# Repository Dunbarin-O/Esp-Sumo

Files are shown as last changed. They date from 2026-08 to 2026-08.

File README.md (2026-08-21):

# Esp-Sumo
## Design Story

Building a custom mini-sumo robot sounded straightforward until i tried try wiring one together. Early in the process, I realized that relying on a disconnected stack of off-the-shelf motor drivers, sensor breakout boards, and external voltage regulators created a fragile spiderweb of jumper wires that easily disconnected during testing also pretty ugly, very ugly. To build something that stayed together, I decided to design a single, custom printed circuit board (PCB) to integrate every subsystem onto one reliable platform.

My first major challenge was in designing the power architecture. I initially planned to use two high-efficiency switching buck converters in series one to drop the 7.4V battery down to 5V, and a second to drop it further to 3.3V. While it looked ideal in block diagrams, routing the PCB layout showed that the second converter added significant cost, component count, and board space for a negligible boost in efficiency. I pivoted to a hybrid design: a single switching converter for high-draw 5V motor and servo demands, paired with a lightweight linear regulator for sensitive 3.3V logic. This trade-off taught me balancing performance, cost, and simplicity

Seeking external feedback proved equally transformative. After completing my first schematic draft, I had another hardware designer review my work. That peer review exposed critical real-world edge cases I had completely overlooked. To prevent catastrophic shorts during rapid battery swaps, I incorporated a low-resistance P-channel MOSFET switch for instant reverse-polarity protection. I also completely re-evaluated my motor drivers. My initial plan used tiny DRV8220 drivers to keep the board compact, but testing showed their high internal resistance caused severe overheating, and their strict overcurrent protection completely shut off power during motor stalls. I upgraded to dual DRV8870 drivers featuring active "current chopping." Instead of shutting down when pushing against an obstacle, the new drivers automatically throttle current to deliver maximum safe pushing force without crashing the battery rail.

When the fabricated boards arrived, the ESP32-S3 microcontroller powered on and flashed code over USB smoothly on the first try. However, physical hardware quickly revealed real-world oversights that software DRC checks could not predict. I had selected incorrect physical footprints for my pin headers in KiCad, meaning the OLED display could not plug directly into the board and required manual jumper wire reworks. Furthermore, placing every component on a single side made the overall PCB footprint far too large for a compact mini-sumo chassis.

This project proved that a circuit can look entirely correct in a schematic editor while real-world physics, ergonomics, and physical dimensions tell a different story. Version 1 was not perfect, but it served as a functional masterclass in circuit protection, component selection, and practical board layout. For Version 2, I am transitioning to a double-sided component layout to cut the board size in half while correcting all header footprints for a clean, plug-and-play assembly.
---

### Read Further

For detailed technical implementation, schematics, component calculations, PCB layout files, and manufacturing outputs, explore the rest of the repository which is still a wip :

* **`PCB/`** – Native KiCad design files:
  * `Mini_sumo.kicad_sch` – Schematic capture files.
  * `Mini_sumo.kicad_pcb` – PCB trace routing and board layout.
* **`Hardware/`** – Assembly and manufacturing outputs:
  * `Mini_sumo.zip` – Production Gerber & drill files for board fabrication.
  * `combined_bom.csv` – Bill of Materials listing all active and passive components.
  * `positions.csv` – Pick-and-Place (CPL / Centroid) file for automated SMT assembly.
Project is in
 its early stages 

A low-cost, open-source motion control board for ESP32-based robots.
High-performance motor boards are usually expensive or made for just one job. This project is a low-cost, all-in-one board that lets you build precise small robots without needing extra shields or breakout boards.

Applications:

Mini Sumo Robots: Integrated motor control and gyro feedback for rapid opponent tracking and high-torque maneuvers.

Inverted Pendulum / Self-Balancing: Direct IMU integration for low-latency loop control and pitch stabilization.

Heading-Corrected Rovers: Closed-loop yaw monitoring for straight-line differential driving and precise turn angles.

### V1 Key Features

* **Dual High-Current Motor Drivers:** Two TI DRV8870 ICs providing independent PWM speed and direction control, supporting up to 3.6 A peak output per channel.
* **Onboard Motion Sensing:** MPU-6050 6-axis gyroscope and accelerometer connected via I2C for pitch, roll, and yaw feedback.
* **Integrated Diagnostic Display Header:** Dedicated 4-pin I2C header positioned for direct SSD1306 OLED screens (128x64 or 128x32).
* **User Input Controls:** 3 onboard tactical pushbuttons mapped to ESP32 GPIOs for mode selection, calibration, and menu navigation.
* **Built-in Servo Mount & Header:** Dedicated 3-pin PWM servo header (VCC, GND, Signal) with mounting holes integrated directly into the PCB outline (ideal for mini sumo flippers or sensor sweepers).
* **Optimized Power Architecture:** Designed for 2S (7.4V) LiPo input with onboard voltage regulation to safely power the ESP32, OLED, and logic components.
* **Expansion I/O:** Exposed GPIO headers for IR edge sensors, line detectors, or custom sensors.
* **100% Open-Source Hardware:** Full KiCad project files, schematics, PCB layouts, BOM, and manufacturing outputs (Gerbers/CPL) included.

 Top+null+SMT026081362981

| ESP32-S3 GPIO | Schematic net | Actually connected to |
| ---: | --- | --- |
| **GPIO0** | I00 | Boot button **SW3** + 10k pull-up |
| **GPIO1** | D1 | **Right IR sensor** J5 |
| **GPIO2** | D2 | **Left IR sensor** J6 |
| **GPIO3** | D3 | **SW4 button** |
| **GPIO4** | D4 | **Left edge sensor** J8 |
| **GPIO5** | D5 | **Right edge sensor** J10 |
| **GPIO6** | D6 | **SW5 button** |
| **GPIO7** | D7 | **SW6 button** |
| **GPIO8** | D8 | **Left motor driver IN2** |
| **GPIO9** | D9 | **Left motor driver IN1** |
| **GPIO10** | D10 | **J17 breakout pin 1** |
| **GPIO11** | D11 | **Gyro SCL** |
| **GPIO12** | D12 | **Gyro SDA** |
| **GPIO13** | D14 | **Right motor driver IN2** |
| **GPIO14** | D13 | **Right motor driver IN1** |
| **GPIO15** | D15 | **J15 / right motor?** |
| **GPIO16** | D16 | **J11 servo?** |
| **GPIO17** | D17 | **J17 software uvlo** |
| **GPIO18** | D18 | **Servo signal** |
| **GPIO19** | USB_D− | **USB D−** |
| **GPIO20** | USB_D+ | **USB D+** |
| **GPIO21** | — | **Unused** |

 ## Engineering Design Process & Iterations
## Power Design Choice: Dual Buck Converters vs. Buck + LDO

### First Attempt: Two-Stage Buck Regulation
My initial plan was to use two buck converters in series to drop the 7.4V (2S LiPo) battery voltage down to 5V, and then down to 3.3V for the system ICs to maximize energy efficiency.


**The Problem:** Each buck converter requires its own dedicated supporting passives (inductors, filter capacitors, and feedback resistors). Running two switching stages took up too much PCB footprint, added significant routing complexity, and increased the overall Bill of Materials (BOM) cost.

---

### Final Solution: Single Buck + 3.3V LDO Regulator
I simplified the power tree by keeping a single buck converter for the 5V rail and replacing the second buck stage with a straightforward 3.3V Low-Dropout (LDO) linear regulator.
 

## Peer Design Review: Power & Protection Enhancements

Following the V1 layout release, a community hardware review identified several critical power delivery and protection improvements to increase reliability:

### 1. Battery Input & System Protection
* **Circuit Protection:** The design was solid, but it lacked input safety. Adding an in-line fuse and a reverse-polarity protection circuit (e.g., a P-channel MOSFET or ideal diode) on the 2S LiPo rail is essential to prevent permanent board failure from accidental battery misplugs during quick pit stops.
* **Input Bulk Decoupling:** The 10 µF input capacitor ($C_{\text{IN}1}$) on the buck regulator followed basic bench-supply reference designs. However, long battery wire harnesses introduce parasitic inductance. Upgrading $C_{\text{IN}1}$ to a **47 µF ceramic + 10 µF ceramic paired with a 100 µF electrolytic** lowers High-Frequency ESR and prevents sudden motor current draw from sagging the shared battery rail and browning out the ESP32.

### 2. Switching Regulator Duty Cycle & Stability
* At 7.4 V nominal input, the 5 V buck converter operates near a **0.67 duty cycle** (higher as the LiPo drains). Because the regulator uses peak current mode with fixed internal compensation, switch-node signal integrity must be verified under full load with an oscilloscope to ensure stable loop performance across the entire discharge curve.

### 3. ESD & Port Safety
* Added dedicated **ESD protection IC (USBLC6-2SC6)** on the USB-C $V_{\text{BUS}}$ and $D+/D-$ lines to guard the ESP32 against static discharge during  flashing
* 

### Power Isolation: OR-ing Diode Selection

To prevent backfeeding power between the USB-C 5V supply and the onboard 5V buck converter when both are plugged in simultaneously, I implemented a simple diode OR-ing power path
combining the 2 into 5V Safe and feeding it into ldo.

* **Why Schottky over Silicon Diodes:** Standard silicon rectifiers cause a ~0.7V drop, which would reduce the 5.0V USB rail down to 4.3V—dangerously close to the ESP32's minimum operating threshold and brownout limit.
* **Low Forward Voltage ($V_F$):** Using Schottky diodes keeps the voltage drop under ~0.3V, maintaining a stable supply rail (~4.7V+) for logic components and sensors while safely preventing reverse current flow into your computer's USB port or the buck regulator since a lipo battery is used trying to charge over usb withour any charging circuits could be dangerous.
  
### Front-End Power Protection Circuit

* **P-Channel Reverse Polarity Protection (AO3401A):** Uses a low-$R_{DS(on)}$ P-FET (Q1) to block reverse voltage if the battery is plugged in backward, with a 10V Zener diode (D1) protecting $V_{GS}$ against voltage transients.
* **Overcurrent Safety (F1):** In-line fuse provides hard fault protection against high-current shorts.
* **Active Under-Voltage Monitoring (TPS3702):** Samples battery rail via resistor divider (R21/R22) and outputs a low-battery alert signal (D17) to the ESP32 to prevent over-discharging 2S LiPo cells.
* 
## Picking a driver IC : DRV8220 vs. DRV8870

When designing the motor stage, I needed driver chips capable of handling high startup currents and heavy mechanical loads without overheating or shutting down mid-operation.

### First Attempt: Dual DRV8220 (Compact, but Limited)



My initial plan was to use two compact DRV8220 drivers in the DRL package, but bench analysis revealed major bottlenecks:
* **Thermal Overheating:** High internal resistance ($R_{DS(on)} \approx 1\,\Omega$) and the lack of a thermal pad ($152\,^{\circ}\text{C/W}$ thermal resistance) caused severe heat buildup, limiting continuous current to $< 0.9\text{A}$.
* **Hard Shutdowns:** The $1.76\text{A}$ overcurrent protection (OCP) cuts power entirely during high loads or stalls, stopping the robot mid-operation instead of sustaining torque.
* **Difficult Hand-Soldering:** The tiny leadless DRL package has contacts tucked under the chip, making it extremely difficult to solder, inspect, or rework with a standard soldering iron without bridging.
* **No Built-in Current Sensing:** Lacks a dedicated `ISEN` pin, preventing the use of external sense resistors to measure or actively control motor current.
* **Startup Voltage Glitches & Efficiency Loss:** Logic inputs easily float during microcontroller boot, causing motor twitches. High internal resistance also wastes battery voltage as heat before it reaches the motors.

---

### Final Solution: Dual DRV8870 (High Power & Current Chopping)



I upgraded to two DRV8870 drivers featuring an exposed PowerPAD package and external sense resistors:
* **Hand-Soldering Friendly:** The larger HSOP-8 package with exposed leads **very** important for reliable hand soldering(ended up having it assembled by jcl).
* **Superior Thermals:** Lower internal resistance ($450\,\text{m}\Omega$) paired with a copper thermal pad handles up to $3.6\text{A}$ peak current safely.
* 

* **Smart Current Chopping ($I_{\text{TRIP}}$):** Instead of shutting down completely during a stall, the driver uses parallel sense resistors ($R17 - R20$) totaling $0.2\,\Omega$ to limit current automatically:
  $$I_{\text{TRIP}} = \frac{V_{\text{REF}}}{10 \times R_{\text{ISEN}}} = \frac{3.3\text{V}}{10 \times 0.2\,\Omega} = 1.65\text{A}$$
  When pushing heavy loads, the chip acts like an automatic safety valve "chopping" current to maintain pushing force without tripping power failures or browning out the battery rail.
* **Brush Noise Suppression:** Added $0.1\,\mu\text{F}$ ceramic capacitors ($C2, C5$) directly across the motor terminals to absorb high-frequency electrical noise before it can interfere with the I2C gyroscope or IR floor sensors.

---
## ESP32-S3 Core
i chose the s3 because of its native usb to uart and it simplicity to set up and get working keeping parts cost low


This section covers the core ESP32-S3 microcontroller, its power filtering, boot/reset logic, user UI, and external expansion headers.

### Core Microcontroller (ESP32-S3-WROOM-1)
* **Brain of the Robot:** Handles sensor polling, motor control loops, and peripheral interfaces.
* **Power Decoupling ($C14, C15$):** Placed $0.1\,\mu\text{F}$ and $22\,\mu\text{F}$ capacitors close to the $+3.3\text{V}$ power pin (`Pin 2`) to filter out high-frequency noise and prevent voltage dips when the chip spikes in power draw during wireless tasks or bootup.

---

### Boot Logic & System Buttons
* **Reset Circuit (`SW2`, `EN`):** Pressing `SW2` pulls the `EN` pin to ground to manually restart the microcontroller. 
  * **Debouncing & RC Delay ($R9, C9, C13, R13$):** An RC circuit ($10\,\text{k}\Omega$ pull-up + $1\,\mu\text{F}$ cap) keeps `EN` stable at $+3.3\text{V}$ and prevents electrical noise from causing random micro-resets.
* **Boot Button (`SW3`, `IO0`):** Pressing `SW3` grounds `IO0` on startup to force the ESP32 into USB flashing/bootloader mode. A $10\,\text{k}\Omega$ pull-up resistor ($R14$) ensures `IO0` stays pulled HIGH during normal operation so the chip boots standard code.

---

### User UI & Peripherals
* **User Pushbuttons (`SW4`, `SW5`, `SW6`):** Standard tactile buttons tied to `D3`, `D6`, and `D7`. When pressed, they ground the input line, giving the user programmable controls (e.g., selecting robot fight modes or starting a match).
* **Status LED (`D6`, $R15$):** A debug LED connected to $+3.3\text{V}$ via a $1\,\text{k}\Omega$ current-limiting resistor ($R15$) for visual feedback.

---

### Breakout & Expansion Headers
* **Power Breakouts (`J7`, `J9`):** 4-pin headers giving easy access to GND and $+3.3\text{V}$ rails for external modules, logic analyzers, or multimeters during bench testing.
* **OLED / Sensor Connector (`J17`):** 4-pin connector routing $+3.3\text{V}$, GND, `D10`, and `D17` for plugging in external displays or additional sensor modules.
* **Servo Connector (`J11`):** Dedicated 3-pin header routing $+5\text{V}$, GND, and signal line `D18` to drive a servo motor directly.
## Final Schematic
Mini_sumo (7)

## Board in Hand: Lessons & Physical Hardware Issues

Testing the physical V1 board revealed several layout footprint mismatches and routing constraints that required manual rework:

* **Header Pin Size Mismatches:** The physical pin header footprints for GND, 3.3V, breakout points, and the OLED screen connector were sized incorrectly compared to the actual component pitch/pin sizes.
* **OLED Screen Rework:** Because of the pin size mismatch at header `J17`, the display could not be mounted directly to the PCB. As a temporary workaround, jumper wires had to be manually soldered to interface the screen with the board.
* **Large Board Footprint:** Things **HUGE!**
* **Next Version Improvements:** V2 will utilize double-sided SMT component placement to shrink the board footprint significantly, alongside corrected pin header footprints to eliminate wire jumpers.
##Testing & Peripheral Hardware Validation

 For the buttons 
 i use micropython and thonny the arduiono ide would work just fine
 Thonny.

### Interactive Reflex Game
An interactive MicroPython script that measures reaction times in milliseconds using `time.ticks_ms()` to stress-test button responsiveness under dynamic polling loop conditions.

```python
#MADE FOR MICROPYTHON 
Python
import time
import random
from machine import Pin

# Initialize switches with internal pull-ups (Active LOW)
switches = {
    "SW4 (IO3)": Pin(3, Pin.IN, Pin.PULL_UP),
    "SW5 (IO6)": Pin(6, Pin.IN, Pin.PULL_UP),
    "SW6 (IO7)": Pin(7, Pin.IN, Pin.PULL_UP),
}

print("=" * 40)
print("   MINI-SUMO BUTTON REFLEX CHALLENGE")
print("=" * 40)
print("Instructions: Press the requested button as fast as possible when prompted!\n")

time.sleep(2)

score = 0
total_rounds = 5

for r in range(1, total_rounds + 1):
    print(f"\n--- ROUND {r} of {total_rounds} ---")
    print("Get ready...")
    
    # Wait a random delay (1.5 to 4 seconds) to prevent guessing
    time.sleep(random.uniform(1.5, 4.0))
    
    # Select a target button randomly
    target_name, target_pin = random.choice(list(switches.items()))
    
    print("\n" + "#" * 30)
    print(f"   ---> PRESS {target_name}! <---")
    print("#" * 30)
    
    start_time = time.ticks_ms()
    pressed = False
    
    while not pressed:
        # Check all switches
        for name, pin in switches.items():
            if pin.value() == 0:  # Button pressed (LOW)
                reaction_time = time.ticks_diff(time.ticks_ms(), start_time)
                
                if name == target_name:
                    print(f"SUCCESS! Reaction Time: {reaction_time} ms")
                    score += 1
                else:
                    print(f"WRONG BUTTON! You pressed {name} instead of {target_name}. (+0 pts)")
                
                pressed = True
                
                # Debounce / wait until button is released before moving on
                while pin.value() == 0:
                    time.sleep_ms(10)
                break
                
        time.sleep_ms(5)  # Polling delay

    time.sleep(1)

print("\n" + "=" * 40)
print(f"GAME OVER! Final Score: {score} / {total_rounds}")
if score == total_rounds:
    print("Rating: SUMO GRAND CHAMPION (Lightning fast!)")
elif score >= 3:
    print("Rating: SOLID REFLEXES")
else:
    print("Rating: NEEDS PRACTICE")
print("=" * 40)
```
## Servo Test Script

This script verifies manual servo position control using pushbuttons connected to **GPIO 3** (SW4), **GPIO 6** (SW5), and **GPIO 7** (SW6). It controls the servo signal line on **GPIO 18**. 

* **Note:** i Had to bypass a tight spot on the board by jumping signals directly with jumper wires during testing.

```python
import time
from machine import PWM, Pin

# Servo setup on GPIO 18 (D18)
servo_pin = Pin(18, Pin.OUT)
servo_pwm = PWM(servo_pin)
servo_pwm.freq(50)

# Switches configured with internal pull-ups (Active LOW)
sw4 = Pin(3, Pin.IN, Pin.PULL_UP)  # SW4 -> 0 deg
sw5 = Pin(6, Pin.IN, Pin.PULL_UP)  # SW5 -> 90 deg
sw6 = Pin(7, Pin.IN, Pin.PULL_UP)  # SW6 -> 180 deg

def set_angle(angle):
    angle = max(0, min(180, angle))
    # Map 0-180 deg to 16-bit PWM duty (1638 = 0.5ms, 8192 = 2.5ms at 50Hz)
    duty = int(1638 + (angle / 180.0) * (8192 - 1638))
    servo_pwm.duty_u16(duty)

# Move to center position on boot
set_angle(90)

print("Servo Button Test Active on GPIO 18")
print("Press SW4 (GPIO 3) -> 0° | SW5 (GPIO 6) -> 90° | SW6 (GPIO 7) -> 180°")

while True:
    if sw4.value() == 0:
        set_angle(0)
        print("SW4 Pressed -> Servo set to 0°")
        while sw4.value() == 0:  # Debounce hold
            time.sleep_ms(10)

    elif sw5.value() == 0:
        set_angle(90)
        print("SW5 Pressed -> Servo set to 90°")
        while sw5.value() == 0:
            time.sleep_ms(10)

    elif sw6.value() == 0:
        set_angle(180)
        print("SW6 Pressed -> Servo set to 180°")
        while sw6.value() == 0:
            time.sleep_ms(10)

    time.sleep_ms(20)

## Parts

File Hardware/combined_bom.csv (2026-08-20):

Comment | Designator | Footprint | Quantity | JLCPCB Part #
1uF | C10, C12, C13 | 1206 | 3 | C1848
22uF | C8, C11, C15 | 1210 | 3 | C19659
0.1 uF | C2, C5, C6, C9, C14, C16, C17, C18, C20, C23 | 1206 | 10 | C24497
47 uF | C21, C24 | 1210 | 2 | C76680
100 uF | C3, C22 | 1210 | 2 | C84455
10 uF | C4 | 1206 | 1 | C13585
68pF | C7 | 1206 | 1 | C107178
BZX84C10 | D1 | SOT-23-3 | 1 | C19077470
D_Schottky | D2, D3 | D_SMA-SMB_Universal_Handsoldering | 2 | C2480
LED | D4, D5, D6, D7, ON1 | 0805 | 5 | C84256
Fuse | F1 | 1812 | 1 | C3102
TPS54202HDDCR | IC1 | IC1 | 1 | C527684
USB_C_Receptacle_USB2.0_14P | J3 | USB_C_Receptacle_HCTL_HC-TYPE-C-16P-01A | 1 | C165948
33uH | L1 | L_Bourns_SRP7028A_7.3x6.6mm | 1 | C329385
AO3401A | Q1 | SOT-23 | 1 | C15127
100k | R1, R7 | 1210 | 2 | C620660
1k | R4, R10, R11, R15, R16 | 1210 | 5 | C270888
470 | R9, R12 | 1210 | 2 | C137072
10k | R13, R14, R21, R23 | 1210 | 4 | C422430
0.4 | R17, R18, R19, R20 | 1206 | 4 | C247521
5.1K | R2, R3 | 1210 | 2 | C2933867
30k | R22 | 1210 | 1 | C728373
250k | R5 | 1210 | 1 | C374782
56K | R6 | 1210 | 1 | C147160
13.7KOhms | R8 | 1210 | 1 | C54124
on/off | SW1 | SW_Slide_SPDT_Angled_CK_OS102011MA1Q | 1 | C221530
EN | SW2, SW3, SW4, SW5, SW6 | SW_Push_SPST_NO_Alps_SKRK | 5 | C202388
USBLC6-2SC6 | U2 | SOT-23-6 | 1 | C2827654
TPS3702 | U3 | SOT-23-6 | 1 | C2068031
AP2112K-3.3 | U5 | SOT-23-5 | 1 | C23380830
ESP32-S3-WROOM-1 | U6 | ESP32-S3-WROOM-1 | 1 | C2913202
DRV8870DDA | U7, U8 | Texas_HTSOP-8-1EP_3.9x4.9mm_P1.27mm_EP2.95x4.9mm_Mask2.4x3.1mm_ThermalVias | 2 | C86590
TestPoint | GND, TP1, TP3, TP4, TP5, TP6 | TestPoint_Pad_1.5x1.5mm | 6
Conn_01x01_Pin | J1, J2, J13, J14, J15, J16 | SolderWirePad_1x01_SMD_5x10mm | 6
Edge R | J10 | JST_PH_B3B-PH-K_1x03_P2.00mm_Vertical | 1
Conn_01x04_Socket | J17 | PinHeader_1x04_P1.27mm_Vertical | 1
r ir | J5 | JST_PH_B3B-PH-K_1x03_P2.00mm_Vertical | 1
l ir | J6 | JST_PH_B3B-PH-K_1x03_P2.00mm_Vertical | 1
gnd break out | J7 | PinHeader_1x03_P1.27mm_Vertical | 1
Edge L | J8 | JST_PH_B3B-PH-K_1x03_P2.00mm_Vertical | 1
3V3 breakout | J9 | PinHeader_1x03_P1.27mm_Vertical | 1
servo | SERVO | PinHeader_1x03_P1.27mm_Vertical | 1
OC09600 | U4 | MODULE_OC09600 | 1

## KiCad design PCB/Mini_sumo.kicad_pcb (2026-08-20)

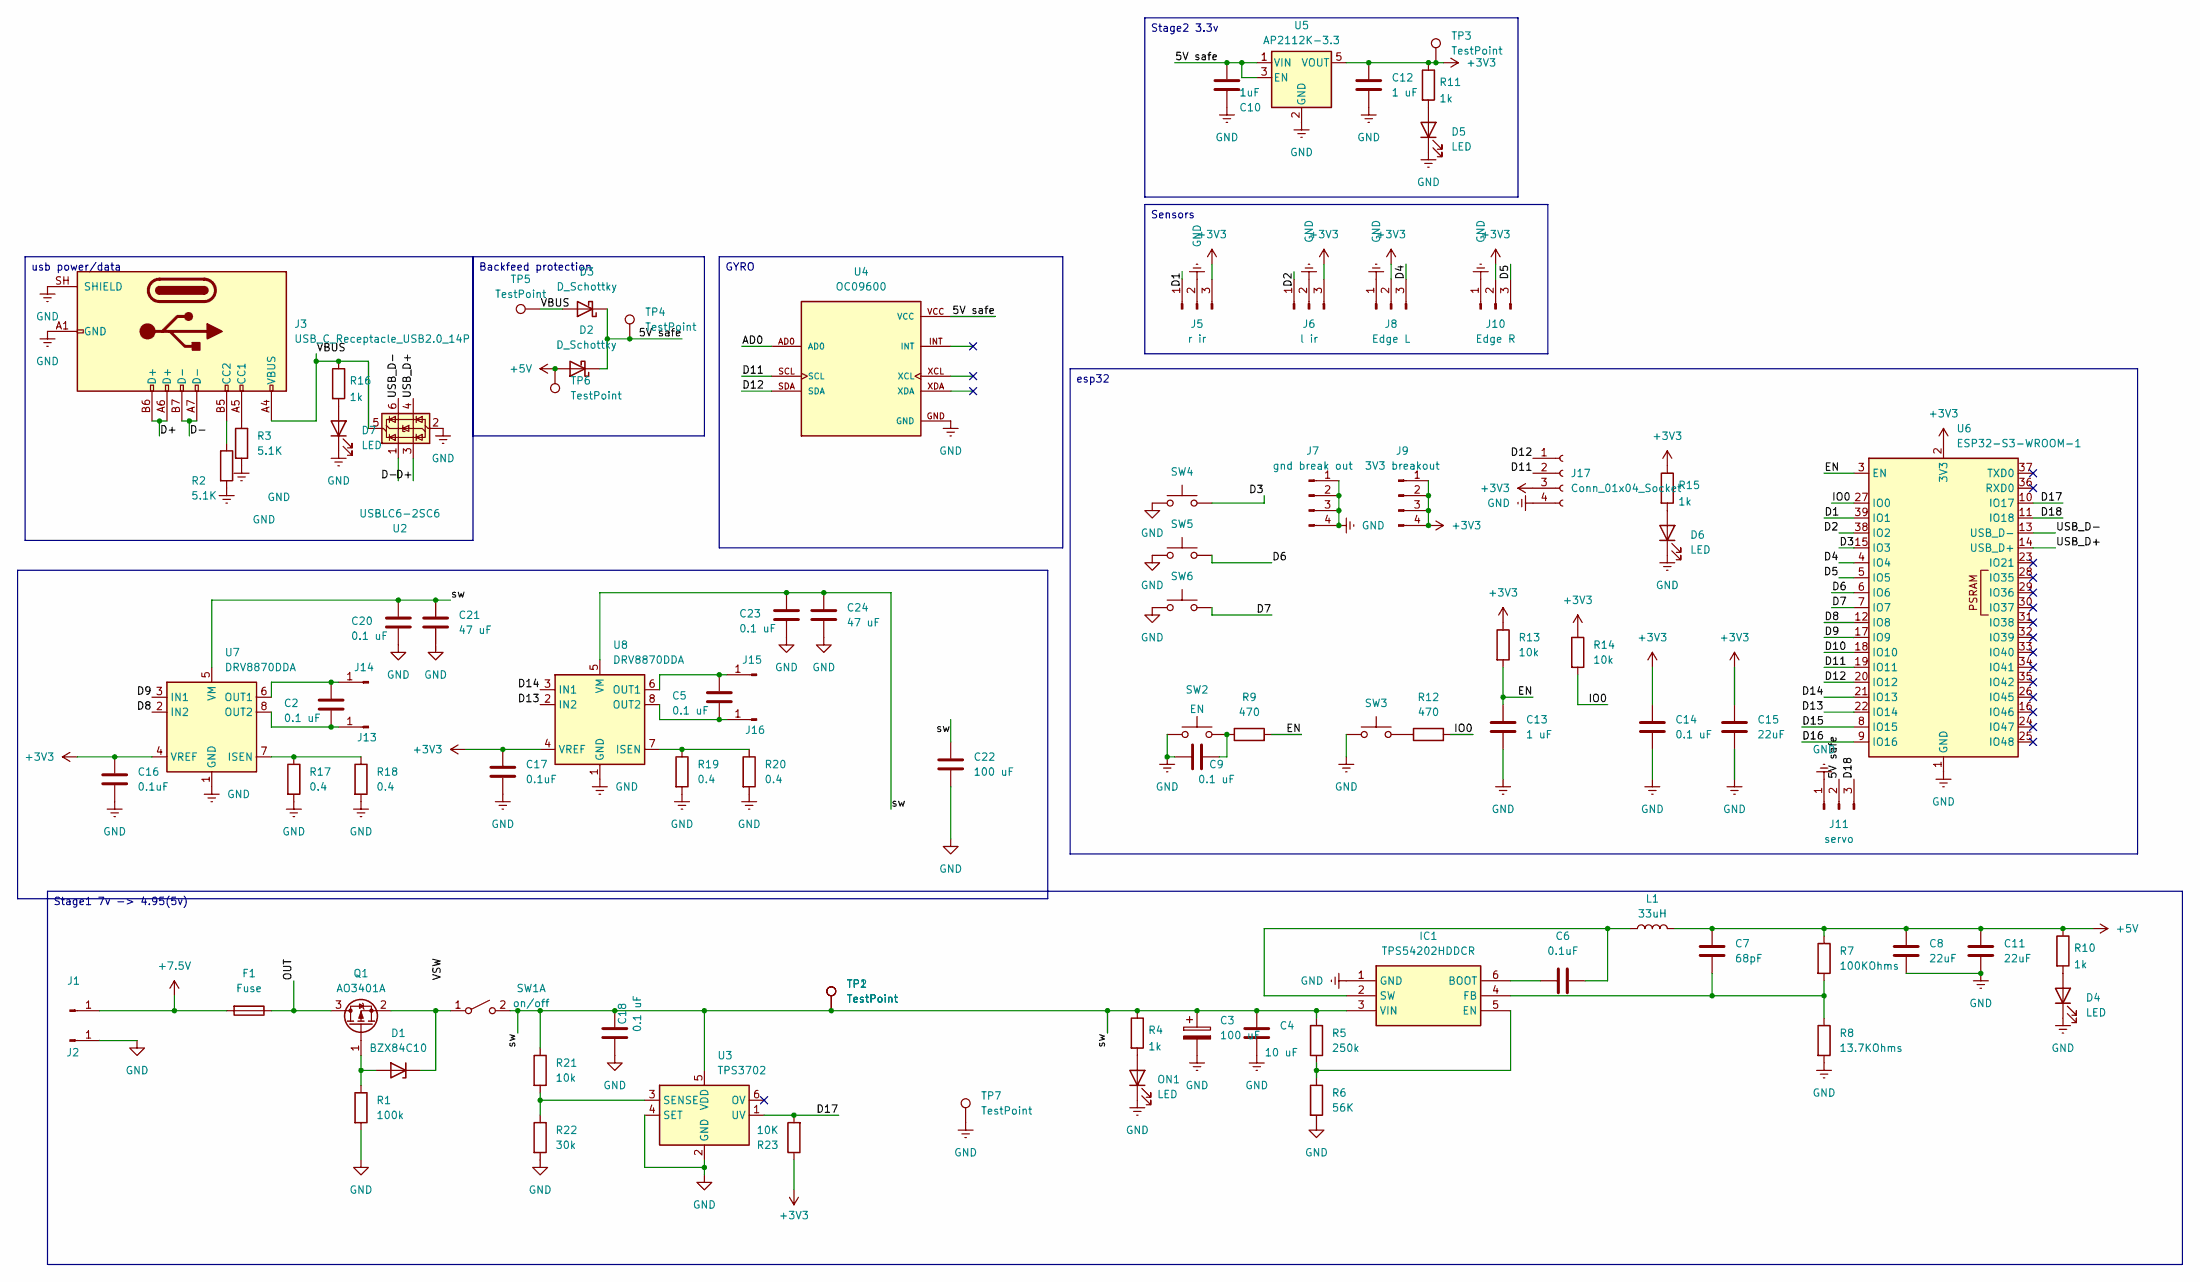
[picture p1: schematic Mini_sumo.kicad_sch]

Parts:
C2, C5, C9, C14, C18, C20, C23: 0.1 uF; C_1206_3216Metric_Pad1.33x1.80mm_HandSolder
C3, C22: 100 uF; C_1210_3225Metric_Pad1.33x2.70mm_HandSolder
C4: 10 uF; C_1206_3216Metric
C6, C16, C17: 0.1uF; C_1206_3216Metric_Pad1.33x1.80mm_HandSolder
C7: 68pF; C_1206_3216Metric_Pad1.33x1.80mm_HandSolder
C8, C11, C15: 22uF; C_1210_3225Metric_Pad1.33x2.70mm_HandSolder
C10: 1uF; C_1206_3216Metric_Pad1.33x1.80mm_HandSolder
C12, C13: 1 uF; C_1206_3216Metric_Pad1.33x1.80mm_HandSolder
C21, C24: 47 uF; C_1210_3225Metric_Pad1.33x2.70mm_HandSolder
D1: BZX84C10; SOT-23-3
D2, D3: D_Schottky; D_SMA-SMB_Universal_Handsoldering
D4, D5, D6, D7: LED; LED_0805_2012Metric_Pad1.15x1.40mm_HandSolder
F1: Fuse; Fuse_1812_4532Metric_Pad1.30x3.40mm_HandSolder
IC1: TPS54202HDDCR; IC1; Mouser Part Number 595-TPS54202HDDCR
J1, J2, J13, J14, J15, J16: Conn_01x01_Pin; SolderWirePad_1x01_SMD_5x10mm
J3: USB_C_Receptacle_USB2.0_14P; USB_C_Receptacle_HCTL_HC-TYPE-C-16P-01A
J5: r ir; JST_PH_B3B-PH-K_1x03_P2.00mm_Vertical
J6: l ir; JST_PH_B3B-PH-K_1x03_P2.00mm_Vertical
J7: gnd break out; PinHeader_1x03_P1.27mm_Vertical
J8: Edge L; JST_PH_B3B-PH-K_1x03_P2.00mm_Vertical
J9: 3V3 breakout; PinHeader_1x03_P1.27mm_Vertical
J10: Edge R; JST_PH_B3B-PH-K_1x03_P2.00mm_Vertical
J11: servo; PinHeader_1x03_P1.27mm_Vertical
J17: Conn_01x04_Socket; PinHeader_1x04_P1.27mm_Vertical
L1: 33uH; L_Bourns_SRP7028A_7.3x6.6mm
ON1: LED; LED_0805_2012Metric_Pad1.15x1.40mm_HandSolder
Q1: AO3401A; SOT-23
R1: 100k; R_1210_3225Metric_Pad1.30x2.65mm_HandSolder
R2, R3: 5.1K; R_1210_3225Metric_Pad1.30x2.65mm_HandSolder
R4, R10, R11, R15, R16: 1k; R_1210_3225Metric_Pad1.30x2.65mm_HandSolder
R5: 250k; R_1210_3225Metric_Pad1.30x2.65mm_HandSolder
R6: 56K; R_1210_3225Metric_Pad1.30x2.65mm_HandSolder
R7: 100KOhms; R_1210_3225Metric_Pad1.30x2.65mm_HandSolder
R8: 13.7KOhms; R_1210_3225Metric_Pad1.30x2.65mm_HandSolder
R9, R12: 470; R_1210_3225Metric_Pad1.30x2.65mm_HandSolder
R13, R14, R21: 10k; R_1210_3225Metric_Pad1.30x2.65mm_HandSolder
R17, R18, R19, R20: 0.4; R_1206_3216Metric
R22: 30k; R_1210_3225Metric_Pad1.30x2.65mm_HandSolder
R23: 10K; R_1210_3225Metric_Pad1.30x2.65mm_HandSolder
SW1: on/off; SW_Slide_SPDT_Angled_CK_OS102011MA1Q
SW2: EN; SW_Push_SPST_NO_Alps_SKRK
SW3, SW4, SW5, SW6: SW_Push; SW_Push_SPST_NO_Alps_SKRK
TP1, TP2, TP3, TP4, TP5, TP6, TP7: TestPoint; TestPoint_Pad_1.5x1.5mm
U2: USBLC6-2SC6; SOT-23-6
U3: TPS3702; SOT-23-6
U4: OC09600; MODULE_OC09600; PARTREV NA
U5: AP2112K-3.3; SOT-23-5
U6: ESP32-S3-WROOM-1
U7, U8: DRV8870DDA; Texas_HTSOP-8-1EP_3.9x4.9mm_P1.27mm_EP2.95x4.9mm_Mask2.4x3.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

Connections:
+3V3: C12.1, C14.1, C15.1, C16.2, C17.2, J5.3, J6.3, J8.2, J9.1, J9.2, J9.3, J9.4, J10.2, J17.3, R11.1, R13.1, R14.1, R15.1, R23.1, TP3.1 (1_1), U5.5 (VOUT), U6.2 (3V3), U7.4 (VREF), U8.4 (VREF)
+5V: C7.1, C8.1, C11.1, D2.2 (A), L1.2, R7.1, R10.1, TP6.1 (1_1)
+7.5V: F1.2, J1.1 (Pin_1_1)
/5V safe: C10.1, D2.1 (K), D3.1 (K), J11.2, TP4.1 (1_1), U4.VCC, U5.1 (VIN), U5.3 (EN); also elsewhere on the board
/AD0: U4.AD0
/D1: J5.1, U6.39 (IO1)
/D2: J6.1, U6.38 (IO2)
/D3: SW4.2, U6.15 (IO3)
/D4: J8.3, U6.4 (IO4)
/D5: J10.3, U6.5 (IO5)
/D6: SW5.2, U6.6 (IO6)
/D7: SW6.2, U6.7 (IO7)
/D8: U6.12 (IO8), U7.2 (IN2)
/D9: U6.17 (IO9), U7.3 (IN1)
/D10: U6.18 (IO10)
/D11: J17.2, U4.SCL, U6.19 (IO11)
/D12: J17.1, U4.SDA, U6.20 (IO12)
/D13: U6.22 (IO14), U8.2 (IN2)
/D14: U6.21 (IO13), U8.3 (IN1)
/D15: U6.8 (IO15)
/D16: U6.9 (IO16)
/D17: R23.2, U3.1 (UV), U6.10 (IO17)
/D18: J11.3, U6.11 (IO18); also elsewhere on the board
/D+: J3.A6 (D+), J3.B6 (D+), U2.3 (I/O2)
/D-: J3.A7 (D-), J3.B7 (D-), U2.1 (I/O1)
/EN: C13.1, R9.2, R13.2, U6.3 (EN)
/IO0: R12.2, R14.2, U6.27 (IO0)
/OUT: F1.1, Q1.3 (D)
/USB_D+: U2.4 (I/O2), U6.14 (USB_D+)
/USB_D-: U2.6 (I/O1), U6.13 (USB_D-)
/VBUS: D3.2 (A), J3.A4 (VBUS), J3.A9 (VBUS), J3.B4 (VBUS), J3.B9 (VBUS), R16.1, TP5.1 (1_1), U2.5 (VBUS)
/sw: C3.1, C4.1, C18.2, C20.1, C21.1, C22.1, C23.1, C24.1, IC1.3 (VIN), R4.1, R5.2, R21.1, SW1.2 (B), TP1.1 (1_1), TP2.1, U3.5 (VDD), U7.5 (VM), U8.5 (VM)
GND: C3.2, C4.2, C8.2, C9.1, C10.2, C11.2, C12.2, C13.2, C14.2, C15.2, C16.1, C17.1, C18.1, C20.2, C21.2, C22.2, C23.2, C24.2, D4.1 (K), D5.1 (K), D6.1 (K), D7.1 (K), IC1.1 (GND), J2.1 (Pin_1_1), J3.A1 (GND), J3.A12 (GND), J3.B1 (GND), J3.B12 (GND), J3.SH (SHIELD), J5.2, J6.2, J7.1, J7.2, J7.3, J7.4, J8.1, J10.1, J11.1, J17.4, ON1.1 (K), R1.2, R2.2, R3.2, R6.2, R8.2, R17.2, R18.2, R19.2, R20.2, R22.2, SW2.1, SW3.1, SW4.1, SW5.1, SW6.1, TP7.1, U2.2 (GND), U3.2 (GND), U3.4 (SET), U4.GND, U5.2 (GND), U6.1 (GND), U6.40 (GND), U6.41 (GND), U7.1 (GND), U7.9 (GND), U8.1 (GND), U8.9 (GND); also elsewhere on the board
unnamed: C9.2, R9.1, SW2.2
unnamed: D1.2 (A), Q1.1 (G), R1.1
unnamed: D1.1 (K), Q1.2 (S), SW1.1 (A)
unnamed: D4.2 (A), R10.2
unnamed: D5.2 (A), R11.2
unnamed: D6.2 (A), R15.2
unnamed: D7.2 (A), R16.2
unnamed: C6.1, IC1.6 (BOOT)
unnamed: IC1.5 (EN), R5.1, R6.1
unnamed: C7.2, IC1.4 (FB), R7.2, R8.1
unnamed: C6.2, IC1.2 (SW), L1.1
unnamed: J3.A5 (CC1), R3.1
unnamed: J3.B5 (CC2), R2.1
unnamed: C2.2, J13.1 (Pin_1_1), U7.8 (OUT2)
unnamed: C2.1, J14.1 (Pin_1_1), U7.6 (OUT1)
unnamed: C5.1, J15.1 (Pin_1_1), U8.6 (OUT1)
unnamed: C5.2, J16.1 (Pin_1_1), U8.8 (OUT2)
unnamed: ON1.2 (A), R4.2
unnamed: R12.1, SW3.2
unnamed: R21.2, R22.1, U3.3 (SENSE)
unnamed: R17.1, R18.1, U7.7 (ISEN)
unnamed: R19.1, R20.1, U8.7 (ISEN)

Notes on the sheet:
usb power/data
Stage1 7v -> 4.95(5v)
Stage2 3.3v
Sensors
GYRO
esp32
Backfeed protection

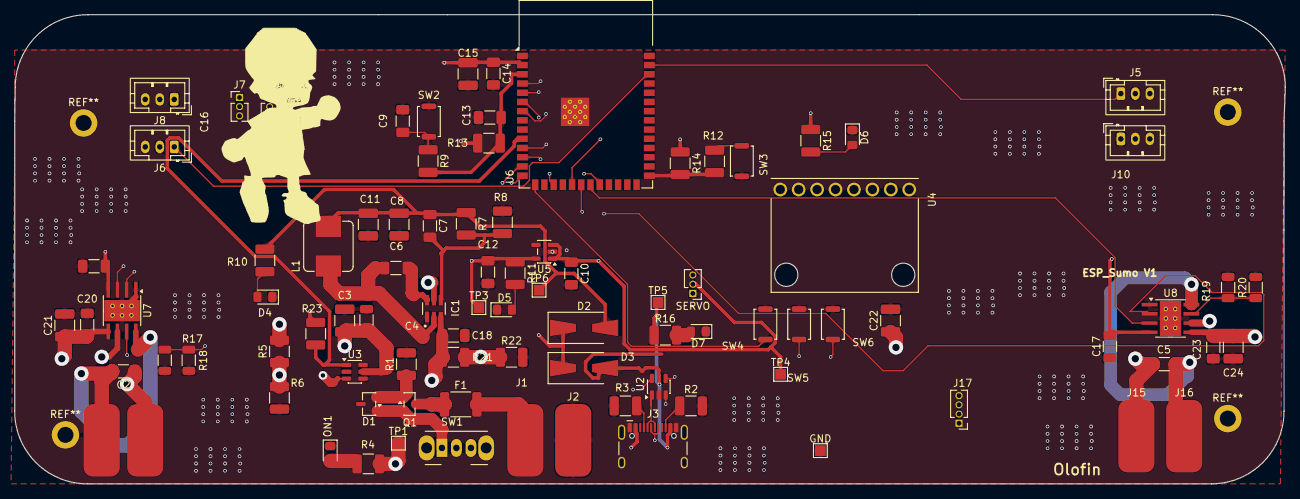
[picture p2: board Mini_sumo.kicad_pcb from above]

Board: 4 copper layers, 175.2 x 64.7 mm, 91 parts (0 on the bottom side), 51 nets.

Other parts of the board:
GND: TestPoint; TestPoint_Pad_1.5x1.5mm
SERVO: servo; PinHeader_1x03_P1.27mm_Vertical

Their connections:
/5V safe: SERVO.2; also elsewhere on the board
/D18: SERVO.3; also elsewhere on the board
GND: GND.1 (1_1), SERVO.1; also elsewhere on the board
